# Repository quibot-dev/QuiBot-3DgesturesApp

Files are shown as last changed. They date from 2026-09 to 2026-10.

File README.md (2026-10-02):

# Qui-Bot H₂O
Documentació oficial i codi del Projecte QuiBot (UPC).

🌐 **Lloc web del projecte:** [https://quibot.upc.edu]

Robot humanoide educatiu que introdueix la programació seqüencial i la química
a infants de primària. Es mou per un tauler de joc amb línies negres, seguint
seqüències d'ordres, i manipula líquids de colors amb dues xeringues.

Admet tres vies de control:

- **Blocs de colors.** S'hi introdueixen cubs de fusta i el robot en llegeix el
  color i executa l'acció corresponent. És la via original del projecte.
- **Gestos.** Un sensor davant la cara reconeix sis ordres de moviment, amb
  confirmació abans d'executar-les.
- **Control remot per Wi-Fi.** El robot serveix una pàgina web que s'obre des
  del navegador de qualsevol telèfon o ordinador de la mateixa xarxa, sense
  instal·lar res.

## Contingut del repositori

| Directori | Contingut |
|---|---|
| `3D/` | Peces en STL, fitxers de disseny, model del conjunt en FreeCAD, captures amb l'orientació d'impressió i els paràmetres de cada perfil |
| `PCB/` | Projecte KiCad, fitxers de fabricació en Gerber, esquema elèctric i vista 3D |
| `src/` | Programa de control, servidor web i programes de verificació |
| `doc/` | Llista de material i memòria del treball |
| `User_manual/` | Guia d'ús del robot per a tallers i vídeo de demostració |

La **guia de muntatge**, de trenta-set passos, és l'annex A de la memòria.

## Maquinari

El control corre sobre una **Raspberry Pi Zero W** muntada sobre una placa
dissenyada per al projecte. Els motors pas a pas es governen amb controladors
A4988 i els polsos es generen per programari amb `pigpio`.

Els sensors són el TCS34725 per al color dels blocs, el PAJ7620U2 per als
gestos, el VL53L0X per a la distància als recipients i dos TCRT5000 per al
seguiment de línia, llegits a través d'un convertidor ADS1115. Els ulls són
dues matrius de LED WS2811.

## Posada en marxa

Cal Raspberry Pi OS Lite de 32 bits. El procediment complet és a l'annex D de
la memòria; en resum:

**1. Busos i pins.** Afegiu a `/boot/firmware/config.txt`:

```
dtparam=i2c_arm=on
dtoverlay=i2c-gpio,bus=3,i2c_gpio_sda=0,i2c_gpio_scl=1
gpio=4,5,6=op,dh
```

La tercera línia imposa nivell alt als pins d'habilitació dels controladors des
de l'arrencada i evita que els motors quedin energitzats i brunzint.

**2. Mòdul d'accés als busos:**

```bash
sudo modprobe i2c-dev
echo i2c-dev | sudo tee -a /etc/modules
```

Reinicieu. `ls /dev/i2c-*` ha de mostrar els dos busos.

**3. Entorn de Python:**

```bash
python3 -m venv ~/.venv
~/.venv/bin/pip install pigpio smbus2 flask rpi_ws281x \
    adafruit-circuitpython-ads1x15 \
    adafruit-circuitpython-tcs34725 \
    adafruit-circuitpython-vl53l0x \
    adafruit-extended-bus
```

**4. Dimoni de control dels pins:**

```bash
sudo systemctl enable --now pigpiod
```

**5. Execució:**

```bash
~/.venv/bin/python3 quibot.py
```

El programa escriu a la sortida l'adreça del control remot, que escolta al
port 8000. Per arrencar-lo automàticament amb la màquina, l'annex D descriu el
servei de systemd corresponent.

Els programes de `src/tests/` permeten comprovar els motors i cada sensor per
separat, cosa que convé fer amb la placa encara accessible.

## Procedència i llicències

L'estructura mecànica i el disseny original del robot provenen del projecte
[Qui-Bot H₂O de La Codornella](https://github.com/lacodornella/QuiBot), d'on
surten també les captures d'orientació d'impressió que es reprodueixen aquí.
Dues peces s'han redissenyat i la placa de control és obra de l'equip del
projecte. El control per gestos, el control remot i la documentació són feina
d'aquest treball.

| Element | Llicència |
|---|---|
| Maquinari: peces 3D, PCB i Gerbers | CERN-OHL-S v2 |
| Programari: codi de control | GPL v3 |
| Documentació: guia de muntatge, BOM i manual | CC BY-SA 4.0 |

Totes tres són recíproques: permeten usar, modificar i redistribuir el
material amb la condició que les obres derivades es publiquin en les mateixes
condicions.

> 📢 **Aviseu-nos si feu servir o adapteu aquest material!**  
> Si teniu pensat replicar el projecte, utilitzar aquest material en la vostra recerca o desenvolupar una versió derivada, us agrairem molt que ens ho feu saber enviant un correu a [quibot@upc.edu](mailto:quibot@upc.edu) o obrint una *Issue* en aquest repositori. Això ens ajuda a fer el seguiment de l'impacte del projecte.

---

## 👥 Autors, Equip i Agraïments

* **Investigadors Principals:** Marta Tarrés i Toni Dorado — Grup de Recerca RISS, Universitat Politècnica de Catalunya (UPC).
* **Desenvolupament i Integració (TFG/TFM):** Pau Anguera Comas 
* **Finançament:** Projecte finançat pel Departament d'Igualtat i Feminismes de la Generalitat de Catalunya (`IFE038/24/000087`).

* ## ⚠️ Avís Legal, Seguretat i Suport

* **Exempció de responsabilitat:** Aquest repositori i tots els seus materials es proporcionen "tal com són" (*AS IS*), amb fins exclusivament docents i de recerca. Els autors i la Universitat Politècnica de Catalunya (UPC) no assumeixen cap responsabilitat per danys directes, indirectes o derivats de la fabricació, muntatge, manipulació o ús dels dissenys, circuits o codis d'aquest projecte.
* **Seguretat mecatrònica:** El dispositiu conté components elèctrics i elements mecànics en moviment. Cal prendre les precaucions de seguretat adients durant la seva manipulació i alimentació elèctrica.
* **Atenció i suport tècnic:** Aquest projecte es manté exclusivament en el marc de les activitats de recerca del grup RISS. L'equip investigador no assumeix cap compromís d'oferir assistència tècnica, suport personalitzat o resolució de peticions a tercers usuaris.

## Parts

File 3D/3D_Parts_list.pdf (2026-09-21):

3D printed parts

Name | Printing time | Plastic (g) | Material | Configuration
1 Arms_motors_support_bottom | 2:49:00 | 24 | PLA negre | QuiBot_2
1 Arms_motors_support_top | 3:11:00 | 27 | PLA negre | QuiBot_2
1 Ball_support | 2:13:00 | 18 | PLA blau | QuiBot_3
1 Ball_support_inferior | 0:23:00 | 3 | PLA blau | QuiBot_3
1 Batteries_lid | 3:15:00 | 29 | PLA blau | QuiBot_3
1 Batteries_support | 8:03:00 | 82 | PLA negre | QuiBot_4
1 Big_pulley | 2:17:00 | 21 | PLA negre | QuiBot_7
1 Big_pulley_mirror | 2:17:00 | 21 | PLA negre | QuiBot_7
1 Block_insert | 5:35:00 | 42 | PLA negre | QuiBot_3
1 Body | 41:46:00 | 311 | PLA blau | QuiBot_3
1 Elbow | 1:20:00 | 9 | PLA negre | QuiBot_6
1 Elbow_mirror | 1:20:00 | 9 | PLA negre | QuiBot_6
1 End_arm_bar | 0:05:00 | 1 | PLA negre | QuiBot_2
1 End_arm_bar | 0:05:00 | 1 | PLA negre | QuiBot_2
1 Extrude_head_1 | 1:59:00 | 16 | PLA taronja | QuiBot_3
1 Extrude_head_1 | 1:59:00 | 16 | PLA taronja | QuiBot_3
1 Extrude_head_2 | 1:58:00 | 24 | PLA taronja | QuiBot_3
1 Extrude_head_2 | 1:58:00 | 24 | PLA taronja | QuiBot_3
1 Extrude_head_3 | 1:40:00 | 19 | PLA taronja | QuiBot_3
1 Extrude_head_3 | 1:40:00 | 19 | PLA taronja | QuiBot_3
1 Eyes_support | 2:32:00 | 23 | PLA negre | QuiBot_1
1 Head | 39:32:00 | 240 | PLA taronja | QuiBot_3
1 Head_back | 7:45:00 | 71 | PLA taronja | QuiBot_3
1 Interior_wheel | 5:58:00 | 83 | PLA taronja | QuiBot_1
1 Interior_wheel_mirror | 5:58:00 | 83 | PLA taronja | QuiBot_1
1 L_Motor_support | 21:16:00 | 147 | PLA blau | QuiBot_3
1 Left_arm_spacing_part | 1:07:00 | 9 | PLA negre | QuiBot_3
1 Left_arm_spacing_part_mirror | 1:07:00 | 9 | PLA negre | QuiBot_3
1 Left_assembly_support | 3:57:00 | 33 | PLA negre | QuiBot_5
1 Left_hall_support (opcional) | 0:55:00 | 5 | PLA negre | QuiBot_3
1 Left_hall_support_mirror (opcional) | 0:55:00 | 5 | PLA negre | QuiBot_3
1 Left_hand | 5:39:00 | 51 | PLA taronja | QuiBot_5
1 Left_hand_mirror | 5:39:00 | 51 | PLA taronja | QuiBot_5
1 Line_sensors_support | 0:49:00 | 5 | PLA negre | QuiBot_5
1 Programming_block_magnets_union | 0:21:00 | 3 | PLA taronja | QuiBot_3
1 Pusher_1 | 0:38:00 | 4 | PLA negre | QuiBot_5
1 Pusher_1_mirror | 0:39:00 | 4 | PLA negre | QuiBot_5
1 Pusher_2 | 0:32:00 | 4 | PLA negre | QuiBot_5
1 Pusher_2_mirror | 0:32:00 | 4 | PLA negre | QuiBot_5
1 Pusher_stopper | 0:20:00 | 3 | PLA negre | QuiBot_3
1 Pusher_stopper_top | 1:28:00 | 11 | PLA negre | QuiBot_3
1 R_Motor_support_mirror | 20:32:00 | 143 | PLA blau | QuiBot_3
1 Right_assembly_support_mirror | 4:11:00 | 36 | PLA negre | QuiBot_5
1 Shoulder | 2:26:00 | 19 | PLA negre | QuiBot_6
1 Shoulder_mirror | 2:26:00 | 19 | PLA negre | QuiBot_6
1 Syringe_hall_sensor_support (opcional) | 0:22:00 | 2 | PLA negre | QuiBot_3
1 Syringe_lifter | 3:07:00 | 19 | PLA negre | QuiBot_3
1 Tension_screw_fixing_part | 0:46:00 | 5 | PLA negre | QuiBot_5
1 Transparent_face | 8:27:00 | 81 | PLA transparent | QuiBot_4
1 Union_and_cables_support | 1:00:00 | 8 | PLA negre | QuiBot_2
1 Wheel | 7:04:00 | 93 | PLA negre | QuiBot_2
1 Wheel_mirror | 7:04:00 | 93 | PLA negre | QuiBot_2
Total: | 250:57:00 | 2082

Printer configurations

| | QuiBot_1 | QuiBot_2 | QuiBot_3 | QuiBot_4 | QuiBot_5 | QuiBot_6 | QuiBot_7
Quality | Layer Height | 0.2 | 0.2 | 0.15 | 0.2 | 0.15 | 0.15 | 0.2
| Initial Layer Height | 0.15 | 0.15 | 0.15 | 0.15 | 0.15 | 0.15 | 0.15
Walls | Wall thikness | 0.8 | 0.8 | 0.8 | 2.0 | 2.0 | 0.8 | 0.8
Top/Bottom | Top/bottom pattern | Lines | Lines | Lines | Lines | Lines | Lines | Lines
| Bottom pattern initial layer | Concentric | Lines | Lines | Lines | Lines | Lines | Lines
Infill | Infill density | 10% | 25% | 15% | 15% | 40% | 50% | 25%
Material | Printing temperature | 200ºC | 200ºC | 200ºC | 200ºC | 200ºC | 200ºC | 200ºC
| Speed | 60 mm/s | 40 mm/s | 50 mm/s | 50 mm/s | 50 mm/s | 50 mm/s | 30 mm/s
Support | Generate support | | 1 | 1 | 1 | 1 | 1 | 1
| Support Overhang Angle | | 84º | 84º | 84º | 84º | 84º | 84º

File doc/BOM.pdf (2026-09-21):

Material

Component | Funció | Preu unitari Unitats | Paquet | Cost de compraBotiga | Enllaç
MOVIMENT I TRACCIÓ
Motor pas a pas amb reductor planetari | Tracció de les dues rodes | 31,74 € | 2 | 1 | 63,48 € | Amazon
Sensor de línia TCRT5000 | Seguiment de la línia del tauler | 0,90 € | 2 | 10 | 9,00 € | Amazon
Sensor de distància VL53L0X | Detecció dels recipients | 5,99 € | 1 | 1 | 5,99 € | Amazon
BRAÇOS I XERINGA
Motor pas a pas NEMA 17 | Dos braços i motor de la xeringa | 11,91 € | 3 | 1 | 35,73 € | Amazon
Xeringa de 100 mL amb tub | Aspiració i dosificació del líquid | 3,66 € | 2 | 3 | 10,98 € | Amazon
Barra roscada lineal de 18 cm | Accionament de l'èmbol de les xeringues | 14,99 € | 1 | 1 | 14,99 € | Amazon
Acoblament flexible de 5 a 8 mm | Uneix el motor amb la barra roscada | 3,49 € | 1 | 4 | 13,96 € | Amazon
Politja dentada 2GT de 20 dents | Reducció del moviment dels braços | 9,20 € | 2 | 1 | 18,40 € | Amazon
Corretja GT2 de 200 mm | Transmissió als braços | 1,50 € | 2 | 10 | 15,00 € | Amazon
Rodament 6808ZZ (40×52×7 mm) | Guiatge exterior dels braços | 3,48 € | 2 | 4 | 13,92 € | Amazon
Rodament 604-609 2RS | Guiatge interior dels braços | 1,40 € | 4 | 10 | 14,00 € | Amazon
Rodament lineal LM8UU (8 mm) | Guiatge de les xeringues | 2,42 € | 2 | 12 | 29,04 € | Amazon
Imant de neodimi N52 (8×3 mm) | Unió magnètica del bloc programador | 0,27 € | 4 | 40 | 10,80 € | Amazon
INTERACCIÓ AMB L'USUARI
Sensor de color TCS34725 | Lectura del color dels blocs | 6,00 € | 1 | 2 | 12,00 € | Amazon
Servomotor MG90S | Expulsió dels blocs un cop llegits | 4,50 € | 1 | 2 | 9,00 € | Amazon
Sensor de gestos PAJ7620U2 | Reconeixement dels gestos de la mà | 11,99 € | 1 | 1 | 11,99 € | Amazon
Matriu de LED 8×8 WS2811 | Ulls: única sortida d'informació del robot | 3,24 € | 2 | 3 | 9,72 € | Amazon
CONTROL I ALIMENTACIÓ
Placa de control (fabricació) | Circuit imprès sense components | 227,48 € | 1 | 1 | 227,48 € | PCBWay
Components de la placa | Condensadors, resistències, transistors i capçaleres | 21,94 € | 1 | 1 | 21,94 € | Botiga comercial elect
Controlador de motor A4988 | Un per a cada motor pas a pas | 3,84 € | 5 | 5 | 19,20 € | Amazon
Raspberry Pi Zero W | Unitat de control del robot | 32,90 € | 1 | 1 | 32,90 € | Amazon
Targeta microSD de 32 GB | Sistema operatiu i programa de control | 19,06 € | 1 | 1 | 19,06 € | Amazon
Convertidor A/D ADS1115 | Lectura dels sensors de línia | 3,30 € | 1 | 3 | 9,90 € | Amazon
Bateria externa (20 V i 5 V) | Alimentació del robot per USB-C | 63,64 € | 1 | 1 | 63,64 € | Amazon
Mòdul USB-C Trigger 9-20 V | Negociació de la tensió dels motors | 1,80 € | 2 | 5 | 9,00 € | Amazon
Cable microHDMI a VGA | Consulta de l'adreça del robot en la posada en marxa | 13,99 € | 1 | 1 | 13,99 € | Amazon
ESTRUCTURA I FABRICACIÓ
Filament PLA negre (1 kg) | Impressió de 29 peces (648 g) | 13,99 € | 1 | 1 | 13,99 € | Amazon
Filament PLA blau (1 kg) | Impressió de 6 peces (651 g) | 15,99 € | 1 | 1 | 15,99 € | Amazon
Filament PLA taronja (1 kg) | Impressió de 13 peces (700 g) | 15,99 € | 1 | 1 | 15,99 € | Amazon
Filament PLA transparent (1 kg) | Cara frontal del cap (81 g) | 17,99 € | 1 | 1 | 17,99 € | Amazon
Tub d'alumini 6×4 mm (1 m) ⌀ | Estructura interior; 10 talls | 3,75 € | 2 | 1 | 7,50 € | FesMés
Tub d'alumini 8×6 mm (1 m) ⌀ | Estructura interior; 12 talls | 3,95 € | 2 | 1 | 7,90 € | FesMés
Cargoleria DIN 912, 934 i 125 | 154 cargols, 8 volanderes i 11 femelles | 36,69 € | 1 | 1 | 36,69 € | Inter Metal
ELEMENTS DEL JOC
Lona de plàstic (1,4×2 m) | Tauler per on es mou el robot | 18,00 € | 1 | 1 | 18,00 € | Plàstics Pujol
Cubs de fusta de colors | Blocs de programació | 27,12 € | 1 | 1 | 27,12 € | Amazon
Recipient de plàstic | Contenidors del líquid, als vèrtexs | 3,50 € | 4 | 1 | 14,00 € | Xinos
Tub de silicona 4×6 mm (160 cm) ⌀ | Porta el líquid de les xeringues a les mans | 8,99 € | 1 | 1 | 8,99 € | Amazon
Tub corrugat 32 mm (40 cm) ⌀ | Recobriment exterior dels braços | 8,99 € | 1 | 1 | 8,99 € | Amazon
TOTAL del material que va dins del robot | 799,91 €
TOTAL del desemborsament en compres | 908,26 €

https://amzn.eu/d/0bHJ65rQhttps://amzn.eu/d/0gY5e2cHhttps://amzn.eu/d/0fq382lZ

https://amzn.eu/d/0ahWBRaohttps://amzn.eu/d/0dnn4ptlhttps://amzn.eu/d/0eNuT9R0https://amzn.eu/d/08H7Wn4qhttps://amzn.eu/d/00PCee4bhttps://amzn.eu/d/01LhTFNuhttps://a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

https://amzn.eu/d/04wjB8VRhttps://amzn.eu/d/0ejjzcFlhttps://amzn.eu/d/00GRGy5Vhttps://amzn.eu/d/0fHxGHRr

https://amzn.eu/d/0bKpJpKYhttps://amzn.eu/d/0hONPyERhttps://amzn.eu/d/01s6eHg2https://amzn.eu/d/09HGVsxPhttps://amzn.eu/d/03E54GFUhttps://amzn.eu/d/042zraUVhttps://a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

https://amzn.eu/d/0fHSgWqahttps://amzn.eu/d/04fMypw1
https://amzn.eu/d/03HETHHK
https://amzn.eu/d/05oxmYt9https://www.fesmes.com/perfils-d-alumini/295205004-tub-rodo-alumini-anoditzat-plata-8013237011116.htmlhttps://www.fesmes.com/perfils-d-alum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

https://amzn.eu/d/02Y8XqlD

https://amzn.eu/d/03qYdG2Ohttps://amzn.eu/d/01d3ZOWd

### Cargoleria

Element | Mida | Unitats
Cargol DIN 912 | M3×6 | 14
Cargol DIN 912 | M3×10 | 64
Cargol DIN 912 | M3×12 | 2
Cargol DIN 912 | M3×16 | 13
Cargol DIN 912 | M3×20 | 14
Cargol DIN 912 | M3×30 | 8
Cargol DIN 912 | M3×35 | 21
Cargol DIN 912 | M3×50 | 1
Cargol DIN 912 | M4×20 | 16
Cargol DIN 912 | M4×80 | 1
Volandera DIN 125 | M3 | 8
Femella DIN 934 | M3 | 6
Femella DIN 934 | M4 | 5
Total de cargols | | 154
Total de volanderes | | 8
Total de femelles | | 11

Recompte obtingut de la guia de muntatge (annex A de la memòria).

### Talls de tub

Diàmetre | Llargada | Unitats Funció
⌀8×6 mm | 380 mm | 2 | Travessen el cos i el bloc dels motors
⌀8×6 mm | 125 mm | 2 | Unió del dipòsit amb la base
⌀8×6 mm | 100 mm | 4 | Espatlles
⌀8×6 mm | 65 mm | 3 | Separador de la base i eixos dels braços
⌀8×6 mm | 45 mm | 1 | Tancament del mecanisme del sensor de color
⌀6×4 mm | 310 mm | 1 | Dipòsit de blocs
⌀6×4 mm | 290 mm | 2 | Dipòsit de blocs
⌀6×4 mm | 220 mm | 1 | Dipòsit de blocs
⌀6×4 mm | 105 mm | 4 | Avantbraços
⌀6×4 mm | 65 mm | 2 | Van dins dels de 8, roscats interiorment ⌀

### Repartiment en barres d'un metre (dues de cada diàmetre):

8, barra 1: 380 + 380 + 125 | consum 885 mm, sobren 115 ⌀
8, barra 2: 125 + 100×4 + 65×3 + 45 | consum 765 mm, sobren 235 ⌀
6, barra 1: 310 + 290 + 290 | consum 890 mm, sobren 110 ⌀
6, barra 2: 220 + 105×4 + 65×2 | consum 770 mm, sobren 230 ⌀

Recompte obtingut de la guia de muntatge (annex A de la memòria).

Electrònica de la placa

Component | Característiques | Referència a l'esquema | Unitats | Observacions
Resistència 330 Ω | 1/4 W, axial | R1 | 1
Resistència 220 Ω | 1/4 W, axial | R7, R10 | 2
Resistència 680 Ω | 1/4 W, axial | R3, R8 | 2
Resistència 4,7 kΩ | 1/4 W, axial | R4, R9 | 2
Resistència 10 kΩ | 1/4 W, axial | R5, R6 | 2
Transistor 2N3904 | NPN, TO-92 | Q1, Q2 | 2
Condensador 1000 µF / 6,3 V | Radial 8 mm, pas 2,5 mm ⌀ | C1 | 1
Condensador 470 µF / 35V | Radial 10 mm, pas 5 mm ⌀ | C2 | 1
Condensador 100 µF / 16V | Radial 5 mm, pas 2,5 mm ⌀ | C6 | | 1 Desacoblament del servomotor
Condensador 100 µF / 35V | Radial 6,3 mm, pas 2,5 mm ⌀ | C4 a C5 i C7 a C9 | | 5 Desacoblament dels controladors
Tira de pins mascle 1×3 | Pas 2,54 mm | E_LA1, E_RA1, E_SY1, SERVO1, LED1 | | 5 Finals de cursa, servomotor i ulls
Tira de pins mascle 1×4 | Pas 2,54 mm | M_LW1, M_RW1, M_LA1, M_RA1, M_SY1, CO | 6 Motors i sensor de color
Tira de pins mascle 1×5 | Pas 2,54 mm | G1 | | 1 Sensor de gestos
Tira de pins mascle 1×6 | Pas 2,54 mm | MIC1 | | 1 Micròfon
Tira de pins femella 1×6 | Pas 2,54 mm | DIST1 | | 1 Sensor de distància
Tira de pins mascle 1×7 | Pas 2,54 mm | AMP1 | | 1 Amplificador d'àudio
Tira de pins femella 1×10 | Pas 2,54 mm | ADC1 | | 1 Convertidor ADS1115
Tira de pins femella 1×20 | Pas 2,54 mm | RASP1 | | 2 Raspberry Pi
Tira de pins femella 1x8 | Pas 2,54 mm | L_WHEEL1, R_WHEEL1, L_ARM1, R_ARM1, | | 10 Dos per controlador

Cost conjunt: 21,94 €
Tots els components són THT

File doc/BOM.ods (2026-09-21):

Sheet: Material
Component | Funció | Preu unitari | Unitats | Paquet | Cost de compra | Botiga | Enllaç
MOVIMENT I TRACCIÓ
Motor pas a pas amb reductor planetari | Tracció de les dues rodes | 31,74 € | 2 | 1 | 63,48 € | Amazon | https://amzn.eu/d/0bHJ65rQ
Sensor de línia TCRT5000 | Seguiment de la línia del tauler | 0,90 € | 2 | 10 | 9,00 € | Amazon | https://amzn.eu/d/0gY5e2cH
Sensor de distància VL53L0X | Detecció dels recipients | 5,99 € | 1 | 1 | 5,99 € | Amazon | https://amzn.eu/d/0fq382lZ
BRAÇOS I XERINGA
Motor pas a pas NEMA 17 | Dos braços i motor de la xeringa | 11,91 € | 3 | 1 | 35,73 € | Amazon | https://amzn.eu/d/0ahWBRao
Xeringa de 100 mL amb tub | Aspiració i dosificació del líquid | 3,66 € | 2 | 3 | 10,98 € | Amazon | https://amzn.eu/d/0dnn4ptl
Barra roscada lineal de 18 cm | Accionament de l'èmbol de les xeringues | 14,99 € | 1 | 1 | 14,99 € | Amazon | https://amzn.eu/d/0eNuT9R0
Acoblament flexible de 5 a 8 mm | Uneix el motor amb la barra roscada | 3,49 € | 1 | 4 | 13,96 € | Amazon | https://amzn.eu/d/08H7Wn4q
Politja dentada 2GT de 20 dents | Reducció del moviment dels braços | 9,20 € | 2 | 1 | 18,40 € | Amazon | https://amzn.eu/d/00PCee4b
Corretja GT2 de 200 mm | Transmissió als braços | 1,50 € | 2 | 10 | 15,00 € | Amazon | https://amzn.eu/d/01LhTFNu
Rodament 6808ZZ (40×52×7 mm) | Guiatge exterior dels braços | 3,48 € | 2 | 4 | 13,92 € | Amazon | https://amzn.eu/d/0bqTrvEY
Rodament 604-609 2RS | Guiatge interior dels braços | 1,40 € | 4 | 10 | 14,00 € | Amazon | https://amzn.eu/d/056e36mP
Rodament lineal LM8UU (8 mm) | Guiatge de les xeringues | 2,42 € | 2 | 12 | 29,04 € | Amazon | https://amzn.eu/d/0b6RFzTl
Imant de neodimi N52 (8×3 mm) | Unió magnètica del bloc programador | 0,27 € | 4 | 40 | 10,80 € | Amazon | https://amzn.eu/d/05W1UBqO
INTERACCIÓ AMB L'USUARI
Sensor de color TCS34725 | Lectura del color dels blocs | 6,00 € | 1 | 2 | 12,00 € | Amazon | https://amzn.eu/d/04wjB8VR
Servomotor MG90S | Expulsió dels blocs un cop llegits | 4,50 € | 1 | 2 | 9,00 € | Amazon | https://amzn.eu/d/0ejjzcFl
Sensor de gestos PAJ7620U2 | Reconeixement dels gestos de la mà | 11,99 € | 1 | 1 | 11,99 € | Amazon | https://amzn.eu/d/00GRGy5V
Matriu de LED 8×8 WS2811 | Ulls: única sortida d'informació del robot | 3,24 € | 2 | 3 | 9,72 € | Amazon | https://amzn.eu/d/0fHxGHRr
CONTROL I ALIMENTACIÓ
Placa de control (fabricació) | Circuit imprès sense components | 227,48 € | 1 | 1 | 227,48 € | PCBWay
Components de la placa | Condensadors, resistències, transistors i capçaleres | 21,94 € | 1 | 1 | 21,94 € | Botiga comercial electrònica (Manresa)
Controlador de motor A4988 | Un per a cada motor pas a pas | 3,84 € | 5 | 5 | 19,20 € | Amazon | https://amzn.eu/d/0bKpJpKY
Raspberry Pi Zero W | Unitat de control del robot | 32,90 € | 1 | 1 | 32,90 € | Amazon | https://amzn.eu/d/0hONPyER
Targeta microSD de 32 GB | Sistema operatiu i programa de control | 19,06 € | 1 | 1 | 19,06 € | Amazon | https://amzn.eu/d/01s6eHg2
Convertidor A/D ADS1115 | Lectura dels sensors de línia | 3,30 € | 1 | 3 | 9,90 € | Amazon | https://amzn.eu/d/09HGVsxP
Bateria externa (20 V i 5 V) | Alimentació del robot per USB-C | 63,64 € | 1 | 1 | 63,64 € | Amazon | https://amzn.eu/d/03E54GFU
Mòdul USB-C Trigger 9-20 V | Negociació de la tensió dels motors | 1,80 € | 2 | 5 | 9,00 € | Amazon | https://amzn.eu/d/042zraUV
Cable microHDMI a VGA | Consulta de l'adreça del robot en la posada en marxa | 13,99 € | 1 | 1 | 13,99 € | Amazon | https://amzn.eu/d/0bYeHMyn
ESTRUCTURA I FABRICACIÓ
Filament PLA negre (1 kg) | Impressió de 29 peces (648 g) | 13,99 € | 1 | 1 | 13,99 € | Amazon | https://amzn.eu/d/0fHSgWqa
Filament PLA blau (1 kg) | Impressió de 6 peces (651 g) | 15,99 € | 1 | 1 | 15,99 € | Amazon | https://amzn.eu/d/04fMypw1
Filament PLA taronja (1 kg) | Impressió de 13 peces (700 g) | 15,99 € | 1 | 1 | 15,99 € | Amazon | https://amzn.eu/d/03HETHHK
Filament PLA transparent (1 kg) | Cara frontal del cap (81 g) | 17,99 € | 1 | 1 | 17,99 € | Amazon | https://amzn.eu/d/05oxmYt9
Tub d'alumini ⌀6×4 mm (1 m) | Estructura interior; 10 talls | 3,75 € | 2 | 1 | 7,50 € | FesMés | https://www.fesmes.com/perfils-d-alumini/295205004-tub-rodo-alumini-anoditzat-plata-8013237011116.html
Tub d'alumini ⌀8×6 mm (1 m) | Estructura interior; 12 talls | 3,95 € | 2 | 1 | 7,90 € | FesMés | https://www.fesmes.com/perfils-d-alumini/295205004-tub-rodo-alumini-anoditzat-plata-8013237011116.html
Cargoleria DIN 912, 934 i 125 | 154 cargols, 8 volanderes i 11 femelles | 36,69 € | 1 | 1 | 36,69 € | Inter Metal
ELEMENTS DEL JOC
Lona de plàstic (1,4×2 m) | Tauler per on es mou el robot | 18,00 € | 1 | 1 | 18,00 € | Plàstics Pujol
Cubs de fusta de colors | Blocs de programació | 27,12 € | 1 | 1 | 27,12 € | Amazon | https://amzn.eu/d/02Y8XqlD
Recipient de plàstic | Contenidors del líquid, als vèrtexs | 3,50 € | 4 | 1 | 14,00 € | Xinos
Tub de silicona ⌀4×6 mm (160 cm) | Porta el líquid de les xeringues a les mans | 8,99 € | 1 | 1 | 8,99 € | Amazon | https://amzn.eu/d/03qYdG2O
Tub corrugat ⌀32 mm (40 cm) | Recobriment exterior dels braços | 8,99 € | 1 | 1 | 8,99 € | Amazon | https://amzn.eu/d/01d3ZOWd
TOTAL del material que va dins del robot |  |  |  |  | 799,91 €
TOTAL del desemborsament en compres |  |  |  |  | 908,26 €

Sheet: Cargoleria
Element | Mida | Unitats
Cargol DIN 912 | M3×6 | 14
Cargol DIN 912 | M3×10 | 64
Cargol DIN 912 | M3×12 | 2
Cargol DIN 912 | M3×16 | 13
Cargol DIN 912 | M3×20 | 14
Cargol DIN 912 | M3×30 | 8
Cargol DIN 912 | M3×35 | 21
Cargol DIN 912 | M3×50 | 1
Cargol DIN 912 | M4×20 | 16
Cargol DIN 912 | M4×80 | 1
Volandera DIN 125 | M3 | 8
Femella DIN 934 | M3 | 6
Femella DIN 934 | M4 | 5
Total de cargols |  | 154
Total de volanderes |  | 8
Total de femelles |  | 11
Recompte obtingut de la guia de muntatge (annex A de la memòria).

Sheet: Talls de tub
Diàmetre | Llargada | Unitats | Funció
⌀8×6 mm | 380 mm | 2 | Travessen el cos i el bloc dels motors
⌀8×6 mm | 125 mm | 2 | Unió del dipòsit amb la base
⌀8×6 mm | 100 mm | 4 | Espatlles
⌀8×6 mm | 65 mm | 3 | Separador de la base i eixos dels braços
⌀8×6 mm | 45 mm | 1 | Tancament del mecanisme del sensor de color
⌀6×4 mm | 310 mm | 1 | Dipòsit de blocs
⌀6×4 mm | 290 mm | 2 | Dipòsit de blocs
⌀6×4 mm | 220 mm | 1 | Dipòsit de blocs
⌀6×4 mm | 105 mm | 4 | Avantbraços
⌀6×4 mm | 65 mm | 2 | Van dins dels de ⌀8, roscats interiorment
Repartiment en barres d'un metre (dues de cada diàmetre):
⌀8, barra 1: 380 + 380 + 125 consum 885 mm, sobren 115
⌀8, barra 2: 125 + 100×4 + 65×3 + 45 consum 765 mm, sobren 235
⌀6, barra 1: 310 + 290 + 290 consum 890 mm, sobren 110
⌀6, barra 2: 220 + 105×4 + 65×2 consum 770 mm, sobren 230
Recompte obtingut de la guia de muntatge (annex A de la memòria).

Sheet: Electrònica de la placa
Component | Característiques | Referència a l'esquema | Unitats | Observacions
Resistència 330 Ω | 1/4 W, axial | R1 | 1
Resistència 220 Ω | 1/4 W, axial | R7, R10 | 2
Resistència 680 Ω | 1/4 W, axial | R3, R8 | 2
Resistència 4,7 kΩ | 1/4 W, axial | R4, R9 | 2
Resistència 10 kΩ | 1/4 W, axial | R5, R6 | 2
Transistor 2N3904 | NPN, TO-92 | Q1, Q2 | 2
Condensador 1000 µF / 6,3 V | Radial ⌀8 mm, pas 2,5 mm | C1 | 1
Condensador 470 µF / 35V | Radial ⌀10 mm, pas 5 mm | C2 | 1
Condensador 100 µF / 16V | Radial ⌀5 mm, pas 2,5 mm | C6 | 1 | Desacoblament del servomotor
Condensador 100 µF / 35V | Radial ⌀6,3 mm, pas 2,5 mm | C4 a C5 i C7 a C9 | 5 | Desacoblament dels controladors
Tira de pins mascle 1×3 | Pas 2,54 mm | E_LA1, E_RA1, E_SY1, SERVO1, LED1 | 5 | Finals de cursa, servomotor i ulls
Tira de pins mascle 1×4 | Pas 2,54 mm | M_LW1, M_RW1, M_LA1, M_RA1, M_SY1, COL1 | 6 | Motors i sensor de color
Tira de pins mascle 1×5 | Pas 2,54 mm | G1 | 1 | Sensor de gestos
Tira de pins mascle 1×6 | Pas 2,54 mm | MIC1 | 1 | Micròfon
Tira de pins femella 1×6 | Pas 2,54 mm | DIST1 | 1 | Sensor de distància
Tira de pins mascle 1×7 | Pas 2,54 mm | AMP1 | 1 | Amplificador d'àudio
Tira de pins femella 1×10 | Pas 2,54 mm | ADC1 | 1 | Convertidor ADS1115
Tira de pins femella 1×20 | Pas 2,54 mm | RASP1 | 2 | Raspberry Pi
Tira de pins femella 1x8 | Pas 2,54 mm | L_WHEEL1, R_WHEEL1, L_ARM1, R_ARM1, SYRINGE1 | 10 | Dos per controlador
Cost conjunt: 21,94 €
Tots els components són THT

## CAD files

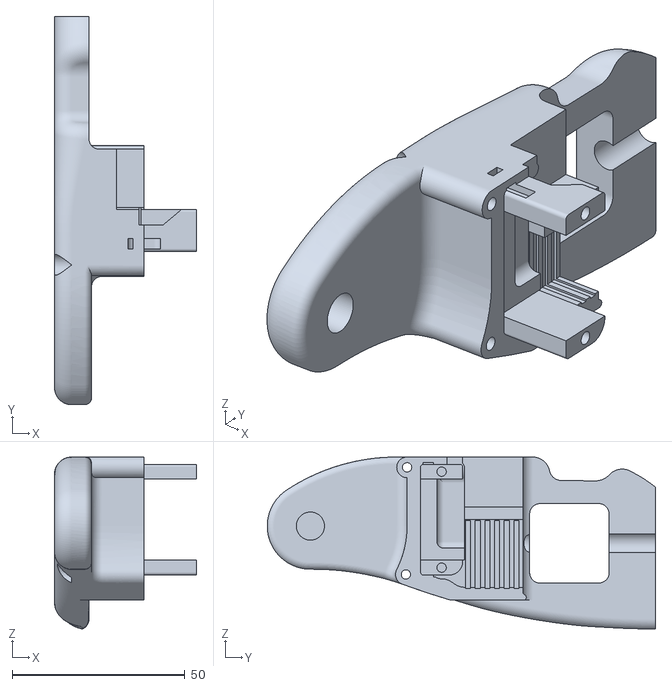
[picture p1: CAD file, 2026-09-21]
3D/STL/Right_assembly_support_mirror.STL
41.2 x 112.5 x 49.8

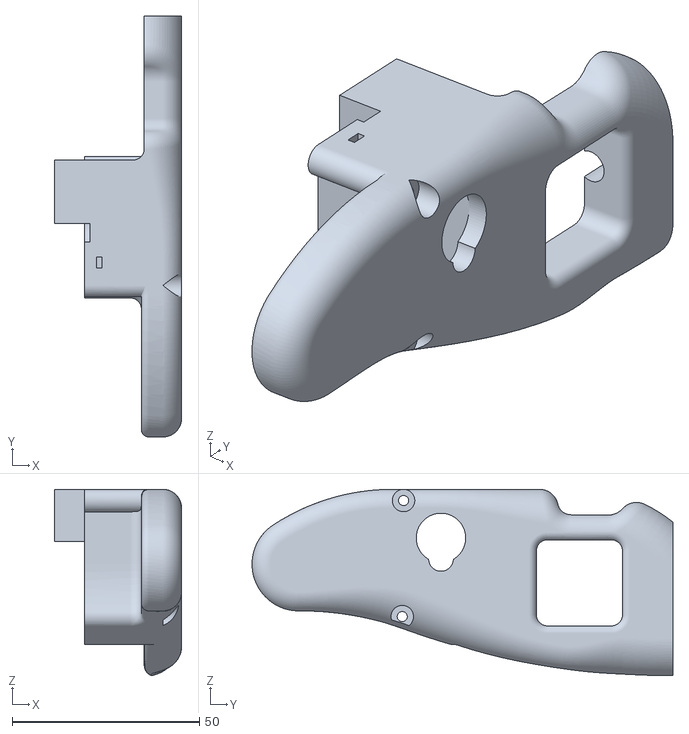
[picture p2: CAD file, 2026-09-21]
3D/STL/Left_assembly_support.STL
34.0 x 112.5 x 49.8

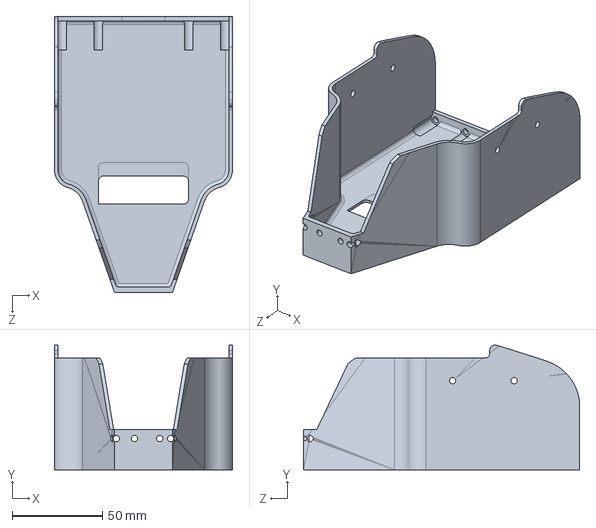
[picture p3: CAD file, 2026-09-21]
3D/SLDPRT/Batteries_support.SLDPRT
98.4 x 69.0 x 152.7 mm

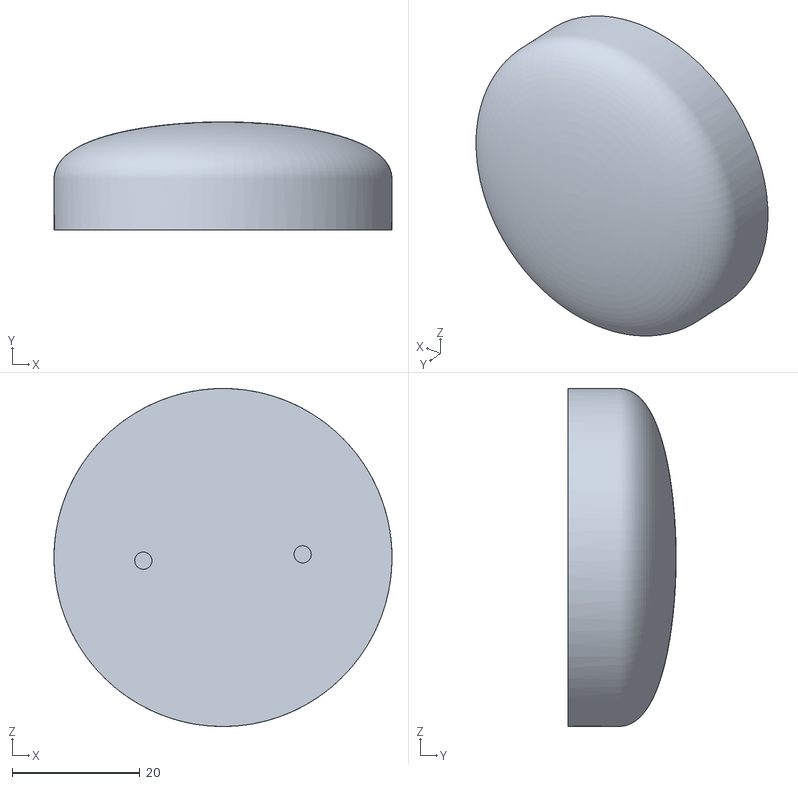
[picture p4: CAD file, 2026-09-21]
3D/STL/Extrude_head_3.STL
53.0 x 17.0 x 53.0

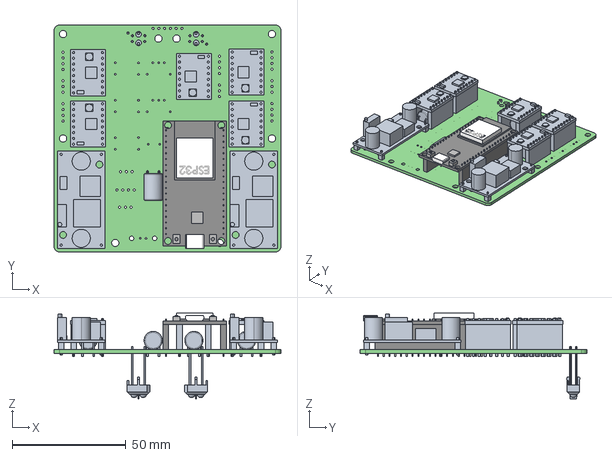
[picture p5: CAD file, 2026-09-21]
PCB/kicad/PCB_QuiBot.step
100.0 x 100.0 x 37.7 mm
_autosave-PCB_QuiBot PCB

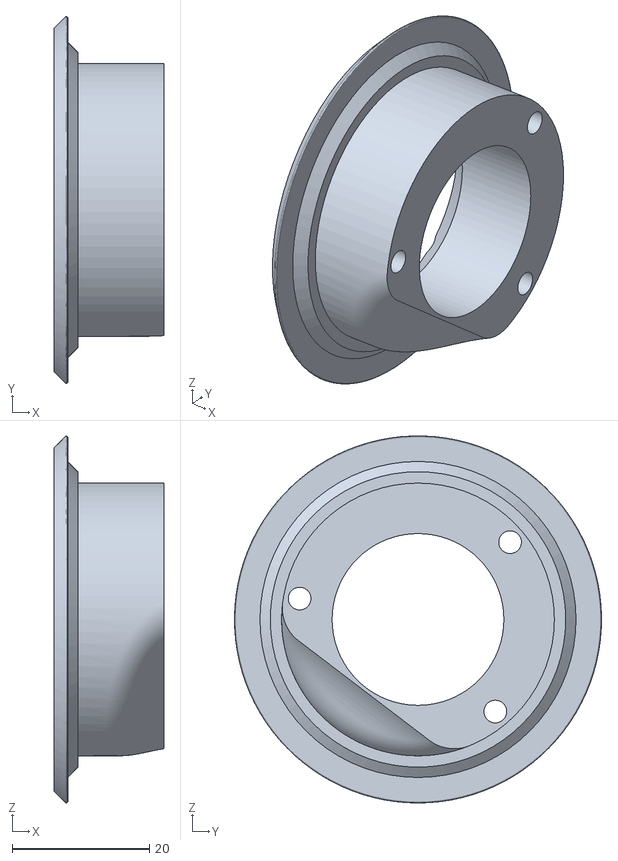
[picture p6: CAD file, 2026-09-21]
3D/STL/Left_arm_spacing_part_mirror.STL
16.0 x 53.4 x 53.4

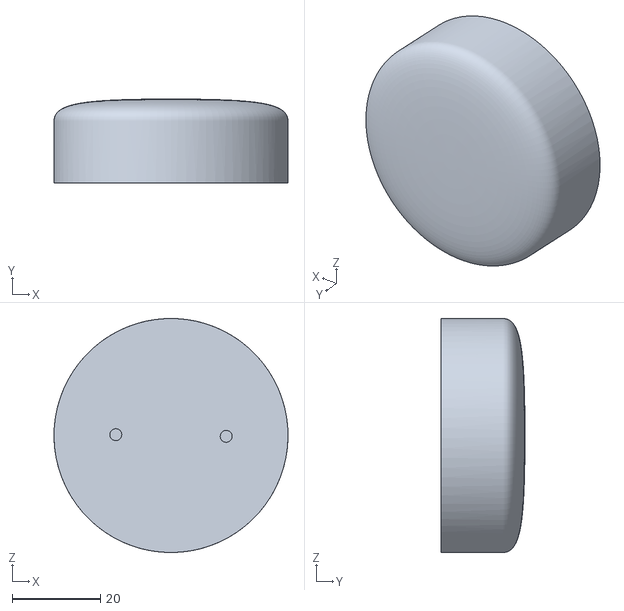
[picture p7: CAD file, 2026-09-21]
3D/STL/Extrude_head_2.STL
53.0 x 19.0 x 53.0

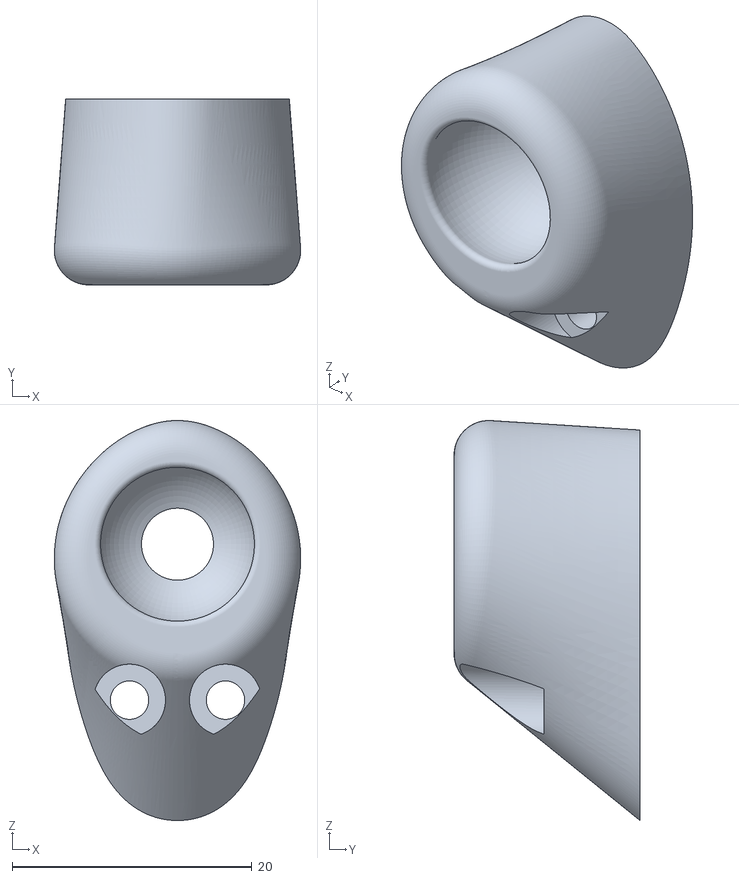
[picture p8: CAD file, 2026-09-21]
3D/STL/Ball_support_inferior.STL
20.5 x 15.5 x 33.3

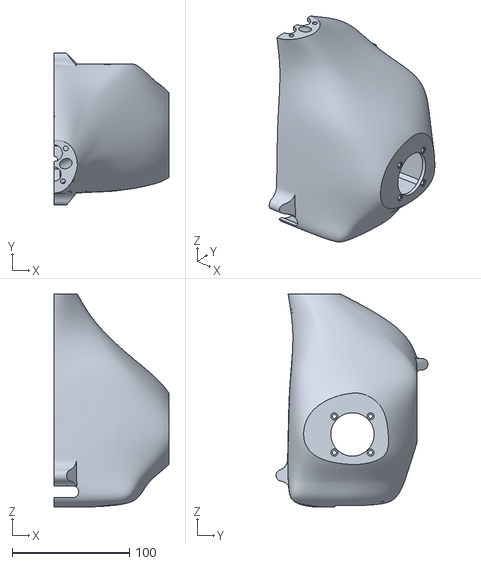
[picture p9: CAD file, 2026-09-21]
3D/STL/R_Motor_support_mirror.STL
98.0 x 129.8 x 182.0

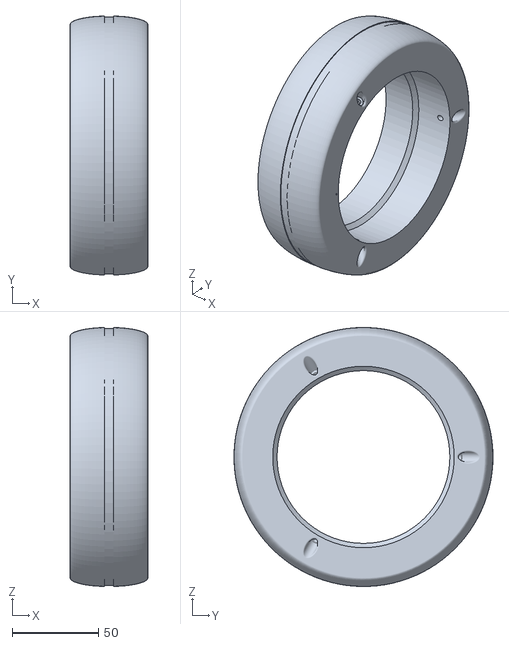
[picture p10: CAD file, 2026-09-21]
3D/STL/Wheel_mirror.STL
45.0 x 149.9 x 149.9

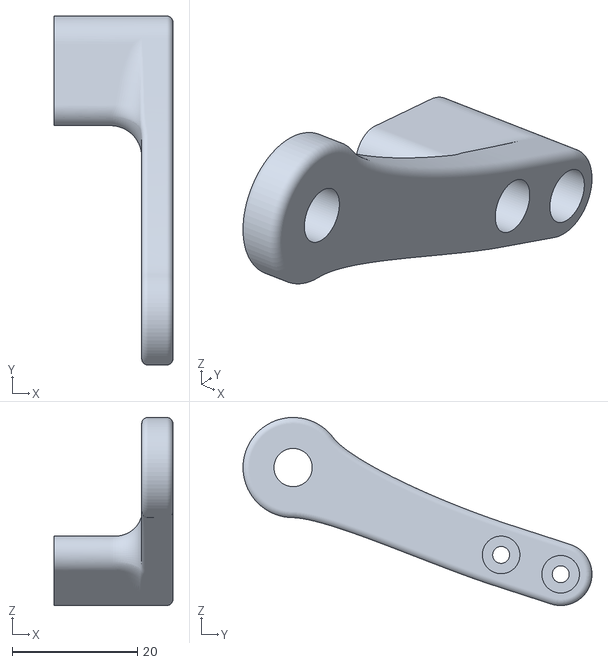
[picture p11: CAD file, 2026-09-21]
3D/STL/Pusher_1_mirror.STL
19.0 x 55.7 x 30.0

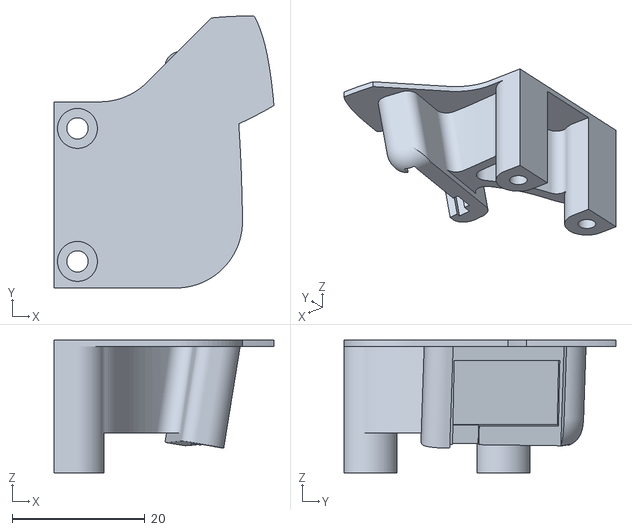
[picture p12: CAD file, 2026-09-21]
3D/STL/Left_hall_support.STL
33.0 x 40.9 x 20.0

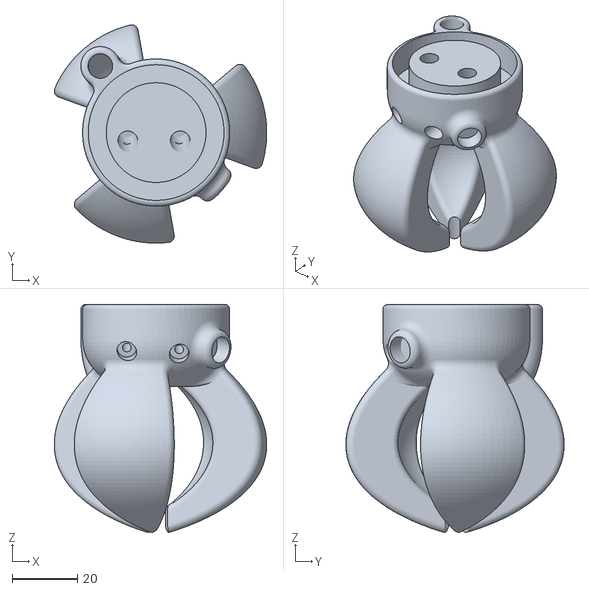
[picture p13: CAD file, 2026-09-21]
3D/STL/Left_hand.STL
65.0 x 66.7 x 69.7

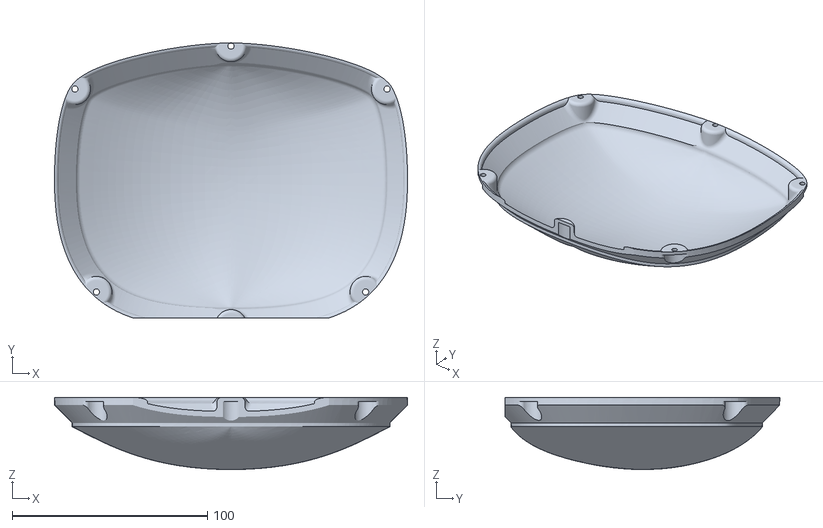
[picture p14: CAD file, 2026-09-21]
3D/STL/Transparent_face.STL
180.9 x 141.0 x 37.0

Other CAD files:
3D/STL/Pusher_1.STL
3D/STL/Arms_motors_support_top.STL
3D/STL/Syringe_hall_sensor_support.STL
3D/STL/Pusher_2.STL
3D/STL/Arms_motors_support_bottom.STL
3D/STL/Ball_support.STL
3D/STL/Batteries_lid.STL
3D/STL/Batteries_support.STL
3D/STL/Big_pulley.STL
3D/STL/Big_pulley_mirror.STL
3D/STL/Block_insert.STL
3D/STL/Body.STL
3D/STL/Elbow.STL
3D/STL/Elbow_mirror.STL
3D/STL/End_arm_bar.STL
3D/STL/Extrude_head_1.STL
3D/STL/Eyes_support.STL
3D/STL/Head.STL
3D/STL/Head_back.STL
3D/STL/Interior_wheel.STL
3D/STL/Interior_wheel_mirror.STL
3D/STL/L_Motor_support.STL
3D/STL/Left_arm_spacing_part.STL
3D/STL/Left_hall_support_mirror.STL
3D/STL/Left_hand_mirror.STL
3D/STL/Line_sensors_support.STL
3D/STL/Programming_block_magnets_union.STL
3D/STL/Pusher_2_mirror.STL
3D/STL/Pusher_stopper.STL
3D/STL/Pusher_stopper_top.STL
3D/STL/Shoulder.STL
3D/STL/Shoulder_mirror.STL
3D/STL/Syringe_lifter.STL
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

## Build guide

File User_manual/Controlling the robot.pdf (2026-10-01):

# Controlar el robot amb gestos i des del mòbil

Qui-Bot H2O • guia ràpida per a tallers

Abans de començar

### 1. Poseu el robot sobre la línia negra del tauler i

endolleu-li la bateria.

### 2. El robot busca sol la posició inicial dels braços i de la

xeringa, i puja els braços perquè no tapin el sensor de gestos. Quan s’encenen els ulls ja està a punt.

3. El robot arrenca en mode blocs, igual que sempre. Els gestos i el comandament des del mòbil s’hi afegeixen: no substitueixen res.

Jugar amb gestos

Feu els gestos amb la mà a uns 15 cm de la cara del robot, posant-vos-hi al davant, cara a cara.

### 1. Saludeu amb la mà per passar del mode blocs al

mode gestos. Els ulls us diuen a quin mode heu entrat. Tornar a saludar us retorna als blocs.

### 2. Feu el gest de l’acció que voleu. Els ulls parpelle-

gen del color de l’acció: el robot ha entès la comanda i espera que la confirmeu.

### 3. Confirmeu amb el gest cap amunt. Apareix un tic

verd i el robot executa l’acció.

Per anul·lar-la, feu el gest cap avall: sortirà una creu vermella. Si no responeu en deu segons, també s’anul·la.

Per què cal confirmar: amb infants al voltant, el sensor veu moltes mans que no li parlen a ell. Sense confirmació el robot es mouria tot sol.

Després de cada acció espereu un segon abans del gest següent. El robot oblida a posta els gestos fets mentre es movia.

Els gestos i què fan

↑ Avança una casella

↓ Recula

← Gira a la dreta

→ Gira a l’esquerra

⟲ Xucla líquid

⟳ Buida líquid

∼ Canvia de mode (saludar)

Els colors dels ulls són els mateixos que els dels blocs: qui ja hi ha jugat no ha d’aprendre res nou.

Dreta i esquerra són les del robot. Com que el teniu al davant, funciona com un mirall: feu el gest cap al vostre costat esquerre i el robot gira cap a la seva dreta. Els colors coincideixen amb els dels blocs.

Significat de la matriu de LED

Parpelleig de color Espero que confirmeu

Tic verd | Confirmat, ho faig
Creu vermella | Anul·lat
Color fix | Executant l’acció

Comandar-lo des del mòbil

1. Connecteu el robot i el mòbil a la mateixa xarxa. En un taller, el més pràctic és compartir dades des del mòbil de qui dirigeix l’activitat.

### 2. Obriu al navegador l’adreça http://adreça:8000. No

cal instal·lar cap aplicació.

Com sabeu l’adreça: la llista de dispositius connectats del punt d’accés del mòbil us la dóna. Si no hi podeu accedir, connecteu una pantalla a la sortida micro-HDMI del robot i llegiu-la-hi.

### 3. Des de la pàgina podeu:

- moure’l i girar-lo amb les fletxes
- xuclar i buidar líquid
- gravar una seqüència d’accions i executar-la després
- canviar entre mode gestos i mode blocs
- calibrar els braços i la xeringa
- apagar el robot

El comandament des del mòbil funciona sempre, tant si el robot és en mode blocs com en mode gestos.

Si alguna cosa va malament

ATURAR

El botó vermell de la pàgina atura el robot a l’instant, encara que estigui a mitja acció.
Un cop aturat podeu triar Continuar la seqüència on era, o Descartar-la i tornar a començar.

Si el robot no respon als gestos, comproveu que els braços no tapin el sensor de la cara i que sigueu en mode gestos: saludeu-lo i mireu-li els ulls.

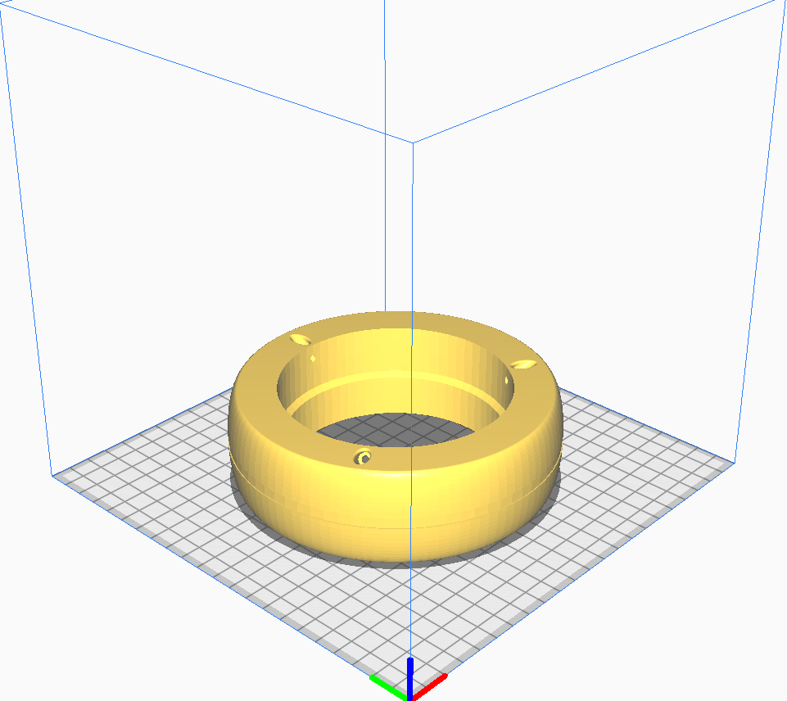
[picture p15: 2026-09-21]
3D/3D printing positioning captions/Wheel.PNG

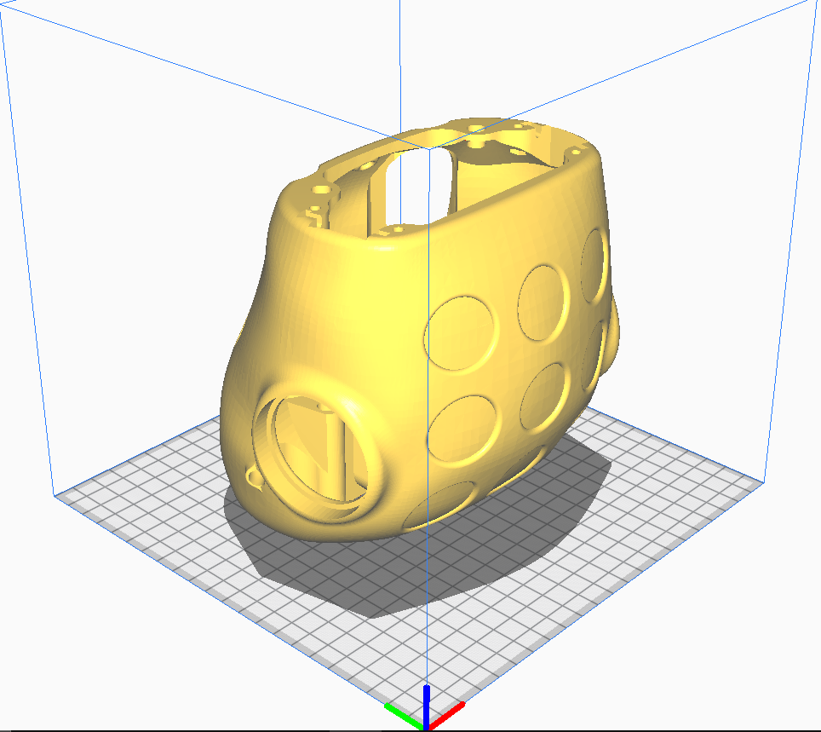
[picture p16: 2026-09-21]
3D/3D printing positioning captions/Body.PNG

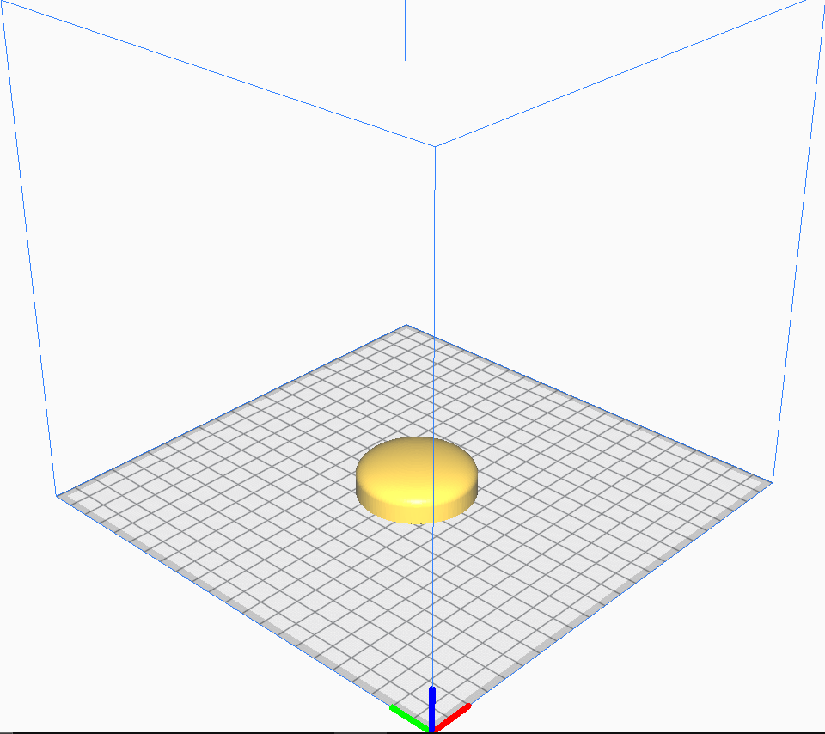
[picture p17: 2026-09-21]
3D/3D printing positioning captions/Extrude_head_3.PNG

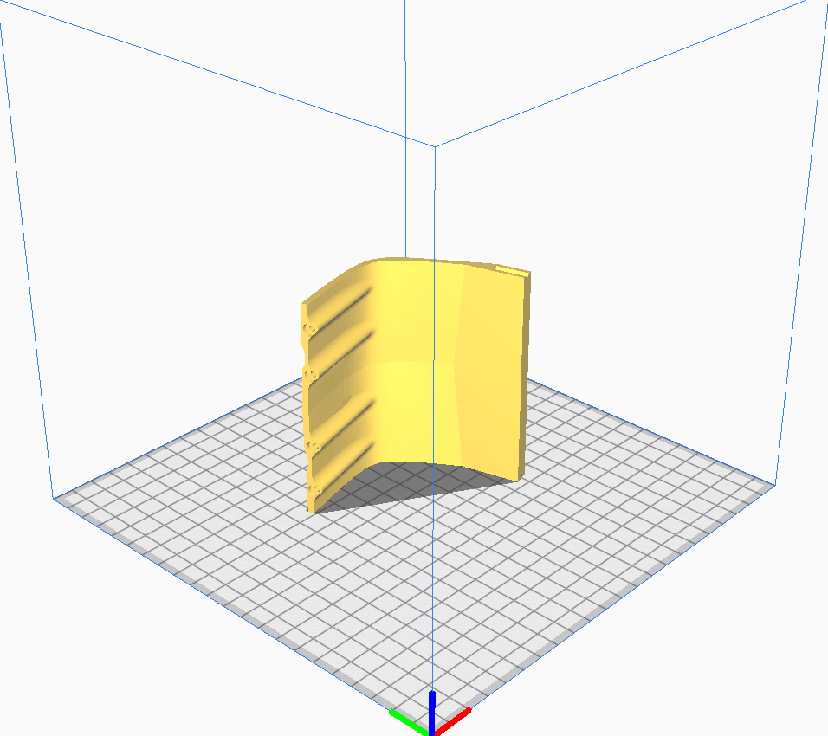
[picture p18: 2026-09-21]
3D/3D printing positioning captions/Batteries_lid.PNG

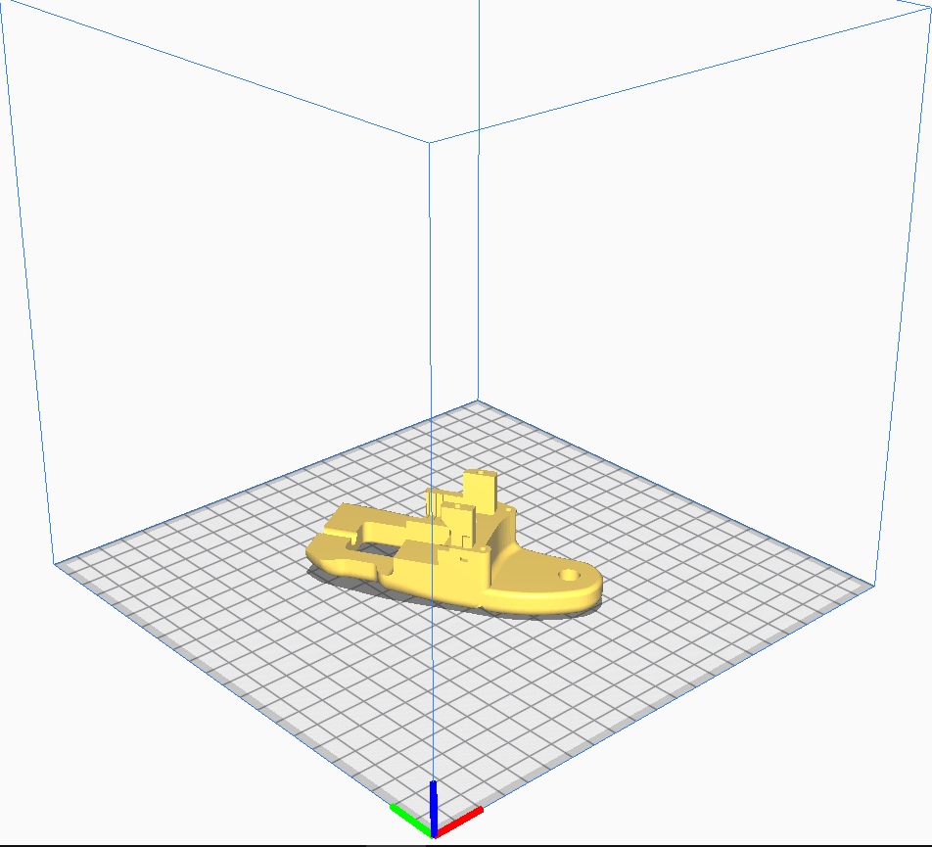
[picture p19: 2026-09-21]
3D/3D printing positioning captions/Right_assembly_support_mirror.PNG

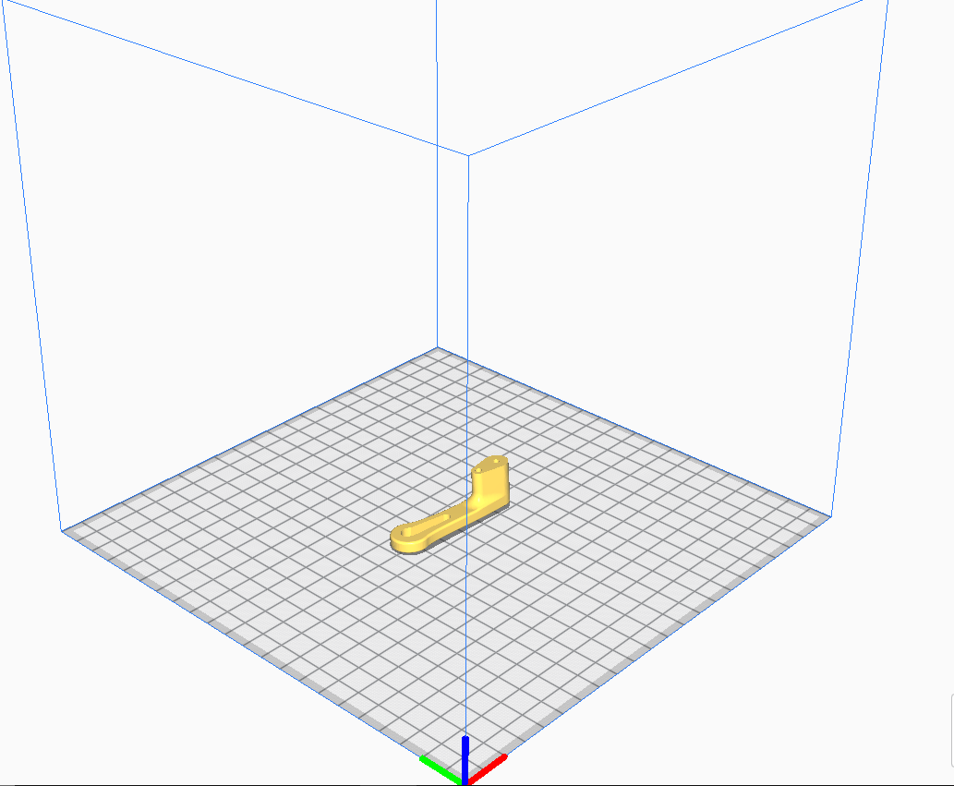
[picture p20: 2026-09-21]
3D/3D printing positioning captions/Pusher_1.PNG

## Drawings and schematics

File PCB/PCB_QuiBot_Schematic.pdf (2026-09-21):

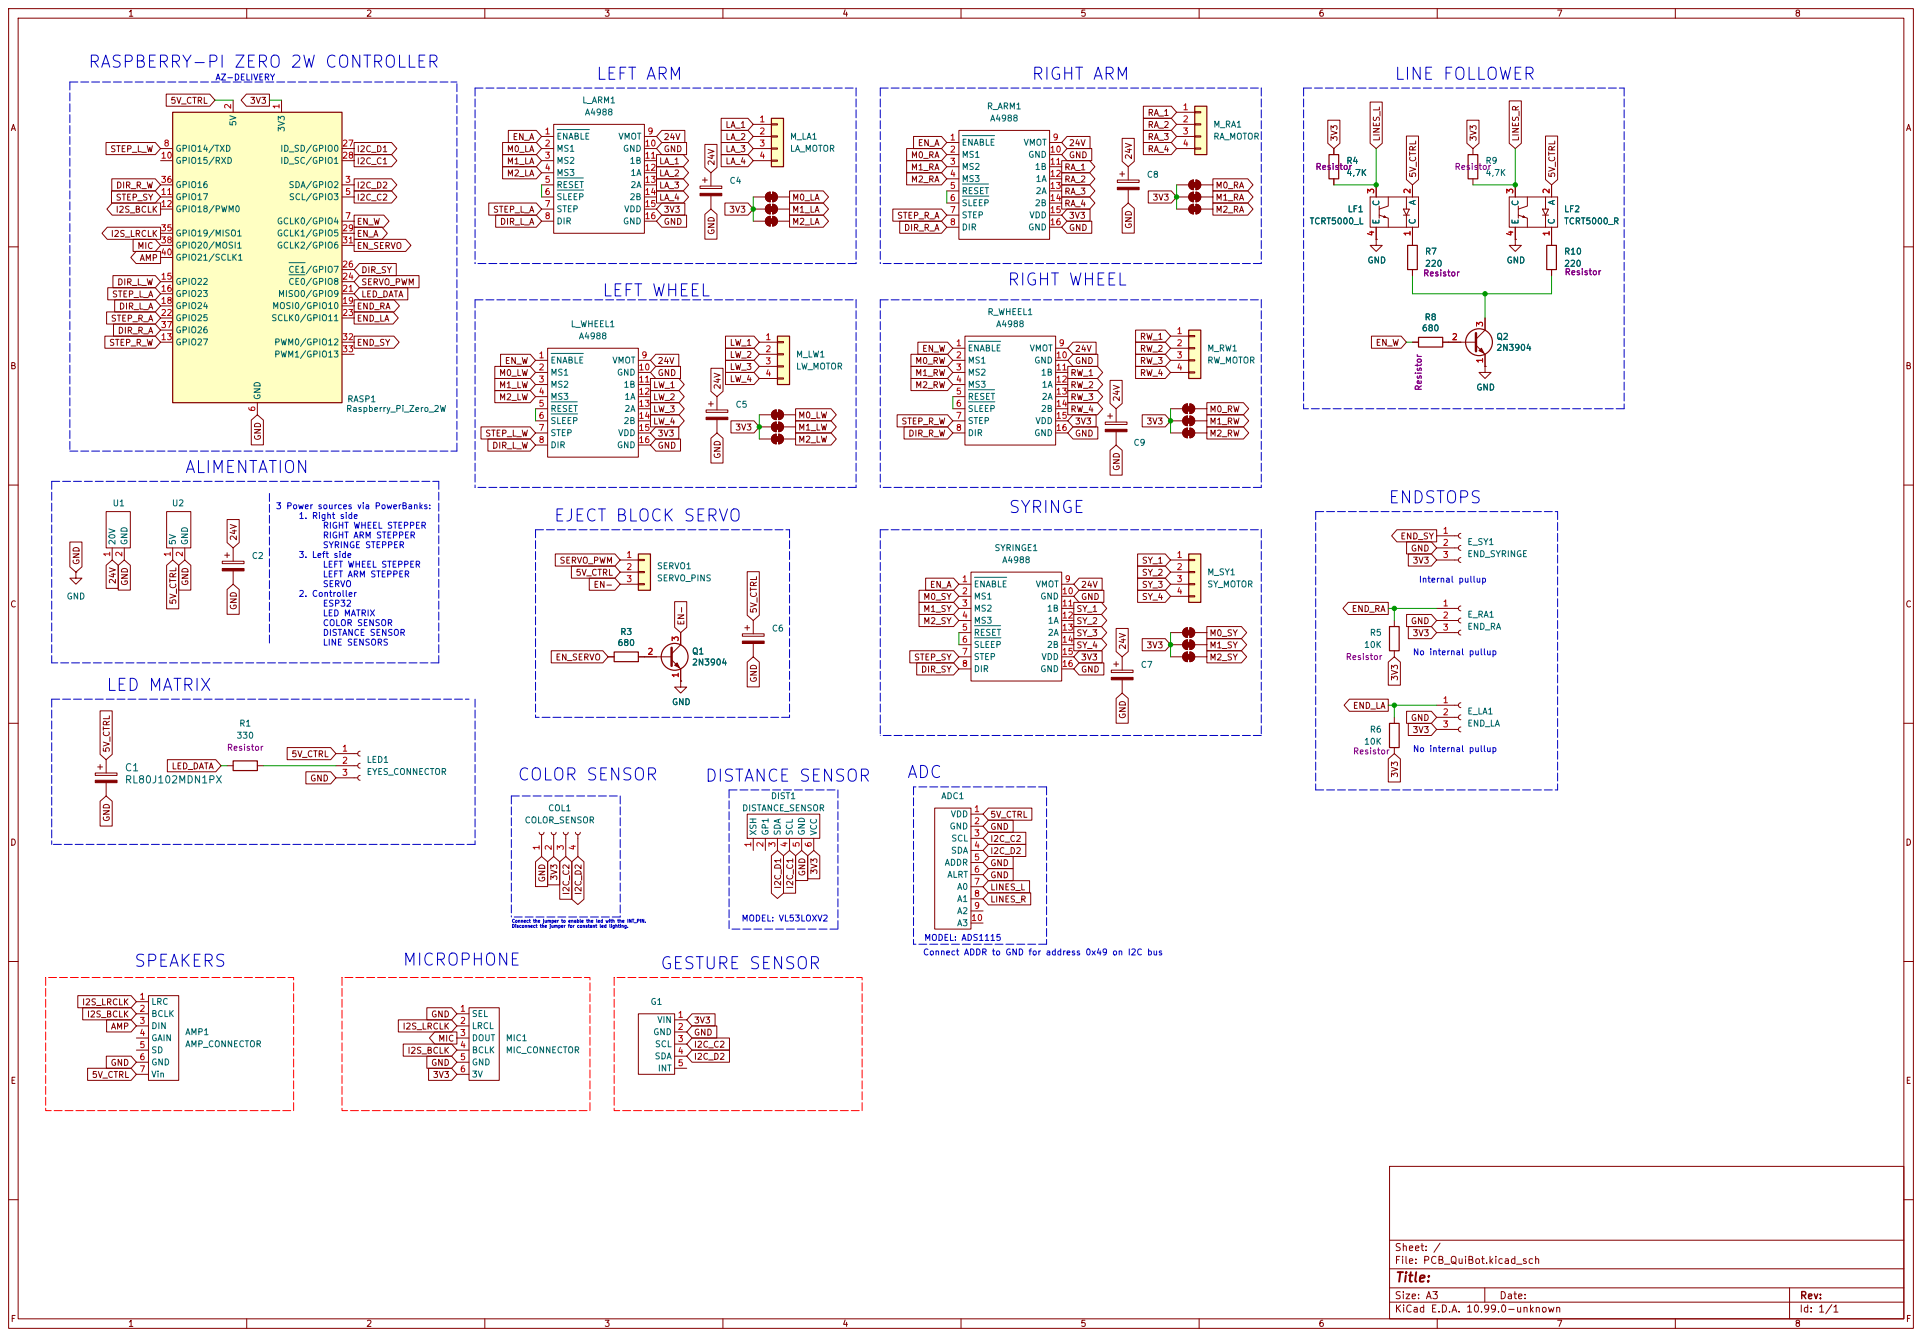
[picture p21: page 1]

RASPBERRY-PI ZERO 2W CONTROLLER

3 Power sources via PowerBanks: 1. Right side RIGHT WHEEL STEPPER

LED MATRIX COLOR SENSOR

Connect the jumper to enable the led with the INT_PIN. Disconnect the jumper for constant led lighting. MICROPHONE

MODEL: ADS1115 Connect ADDR to GND for address 0x49 on I2C bus MODEL: VL53LOXV2

Size: A3 | Rev: | F Date:
KiCad E.D.A. 10.99.0-unknown | Id: 1/1

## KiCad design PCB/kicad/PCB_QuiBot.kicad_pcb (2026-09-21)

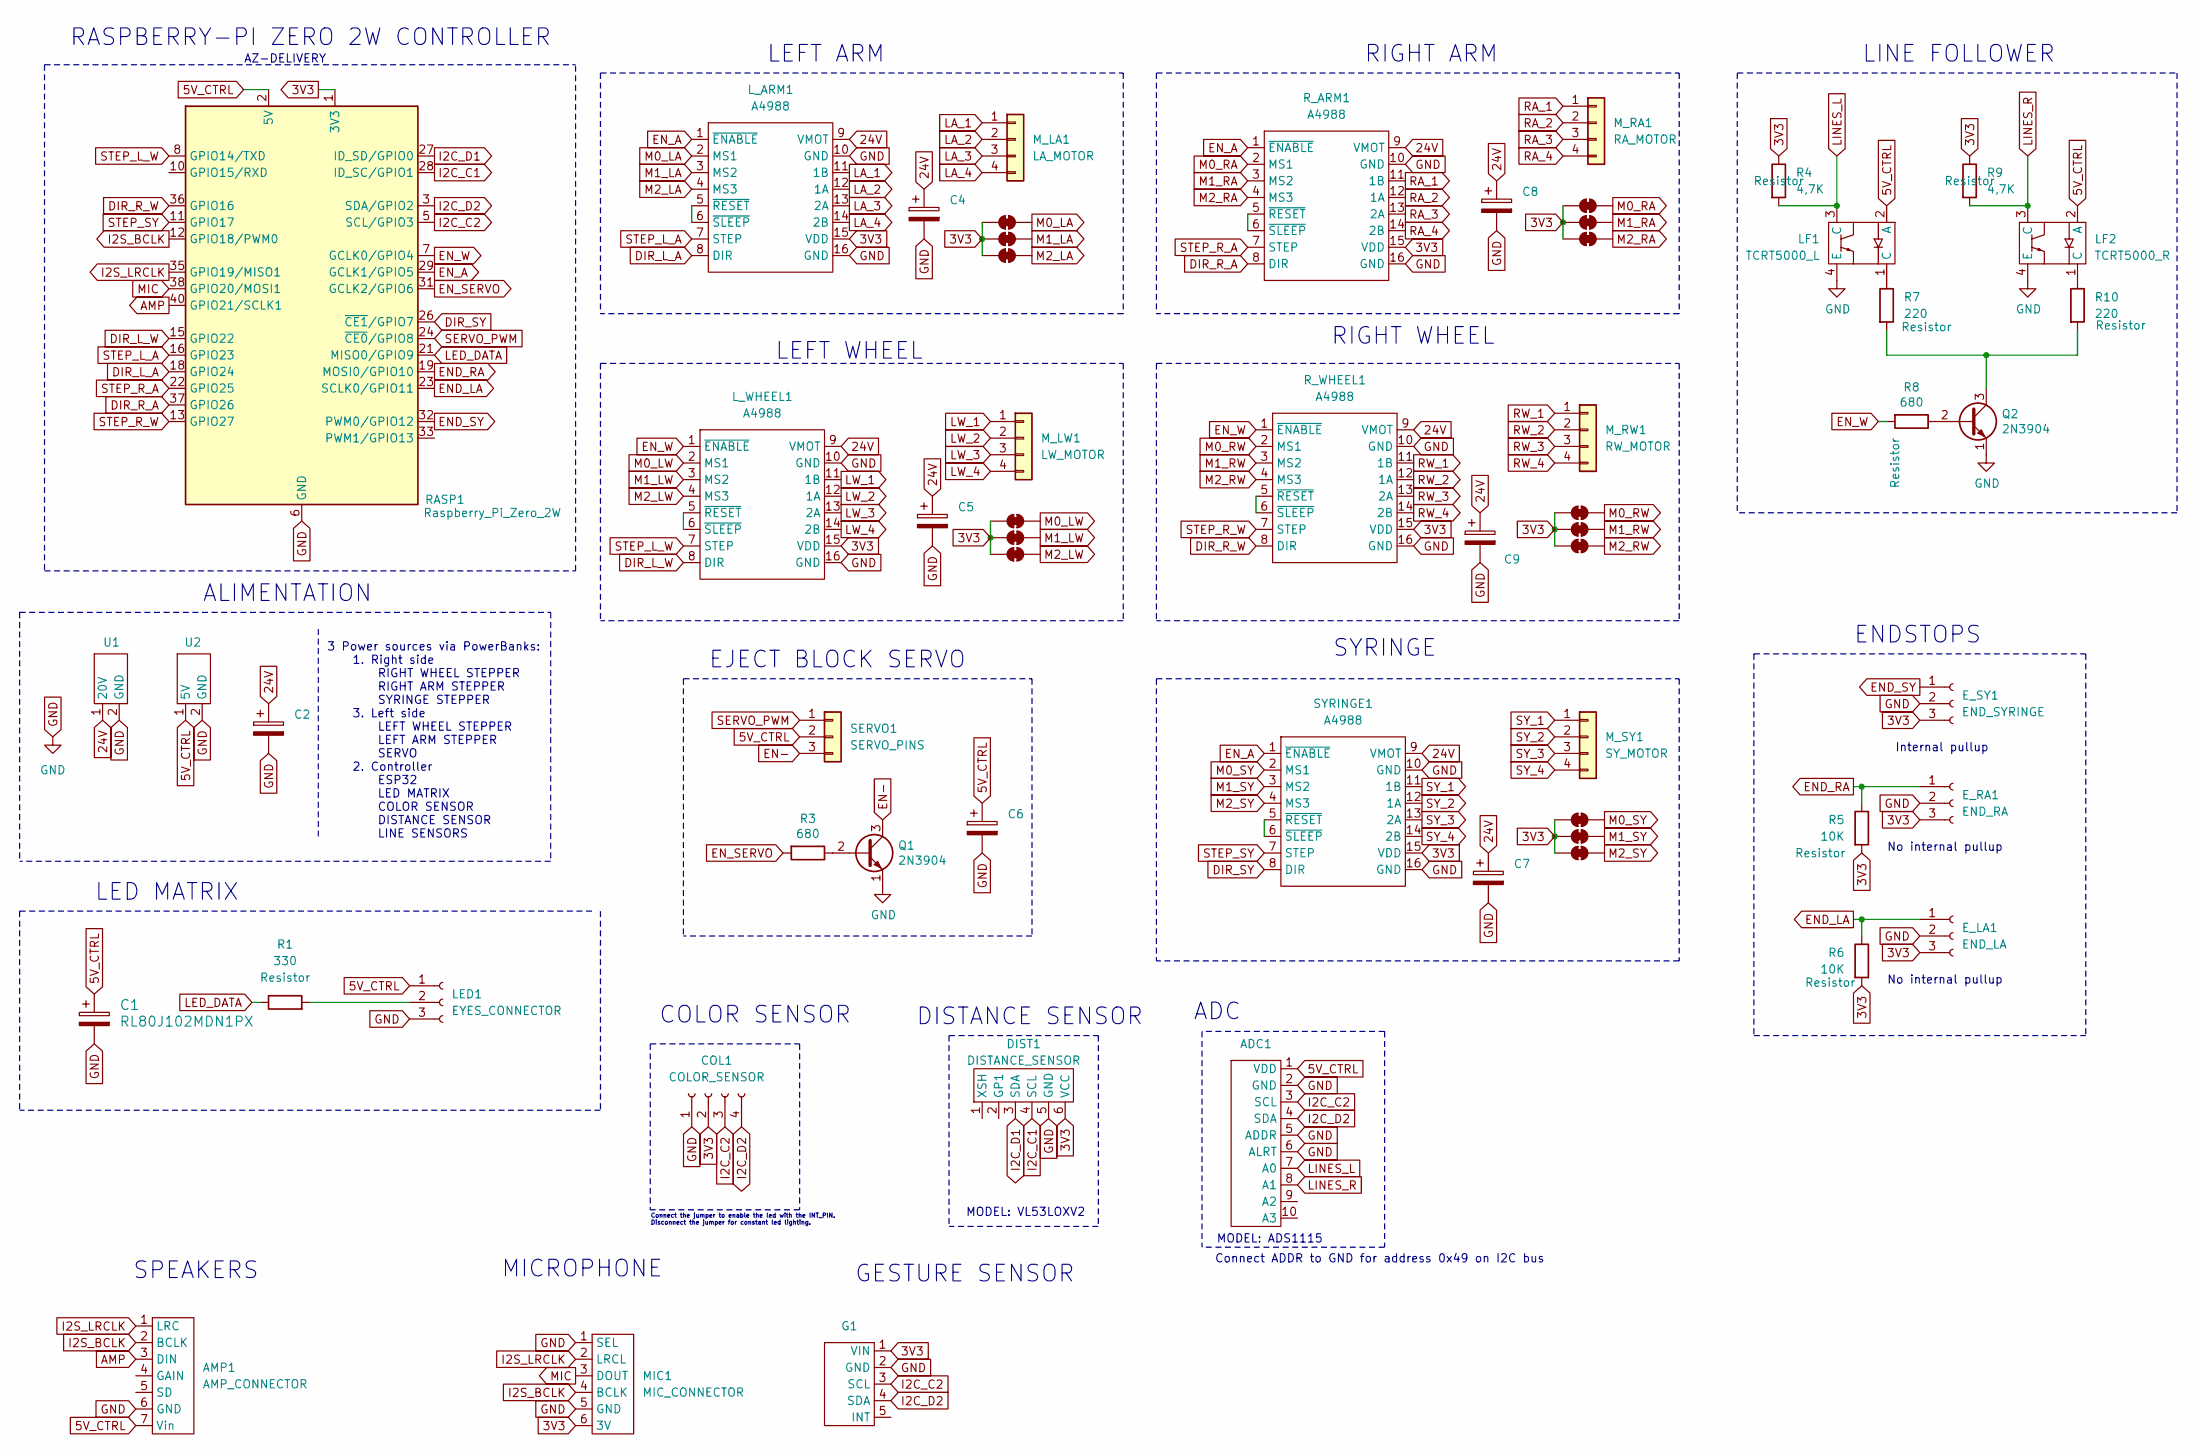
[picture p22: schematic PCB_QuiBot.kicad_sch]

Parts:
ADC1: PinHeader_1x10_P2.54mm_Vertical
AMP1: AMP_CONNECTOR; PinHeader_1x07_P2.54mm_Vertical
C1: RL80J102MDN1PX; CAP_RE5_8X8_NCH
C2: C_Polarized; CP_Radial_D10.0mm_P5.00mm
C4, C5, C6, C7, C8, C9: C_Polarized; CP_Radial_D6.3mm_P2.50mm
COL1: COLOR_SENSOR; PinHeader_1x04_P2.54mm_Vertical
DIST1: DISTANCE_SENSOR; PinHeader_1x06_P2.54mm_Vertical
E_LA1: END_LA; PinHeader_1x03_P2.54mm_Vertical
E_RA1: END_RA; PinHeader_1x03_P2.54mm_Vertical
E_SY1: END_SYRINGE; PinHeader_1x03_P2.54mm_Vertical
G1: PinHeader_1x05_P2.54mm_Vertical
LA0, LA1, LA2: SolderJumper_2_Bridged; SolderJumper-2_P1.3mm_Open_RoundedPad1.0x1.5mm
LED1: EYES_CONNECTOR; PinHeader_1x03_P2.54mm_Vertical
LF1: TCRT5000_L; TCRT5000_Line_follower
LF2: TCRT5000_R; TCRT5000_Line_follower
LW0, LW1, LW2: SolderJumper_2_Bridged; SolderJumper-2_P1.3mm_Open_RoundedPad1.0x1.5mm
L_ARM1: A4988; A4988_stepper_driver
L_WHEEL1: A4988; A4988_stepper_driver
MIC1: MIC_CONNECTOR; PinHeader_1x06_P2.54mm_Vertical
M_LA1: LA_MOTOR; PinHeader_1x04_P2.54mm_Vertical
M_LW1: LW_MOTOR; PinHeader_1x04_P2.54mm_Vertical
M_RA1: RA_MOTOR; PinHeader_1x04_P2.54mm_Vertical
M_RW1: RW_MOTOR; PinHeader_1x04_P2.54mm_Vertical
M_SY1: SY_MOTOR; PinHeader_1x04_P2.54mm_Vertical
Q1, Q2: 2N3904; TO-92_Inline
R1: 330; R_Axial_DIN0207_L6.3mm_D2.5mm_P10.16mm_Horizontal
R3, R8: 680; R_Axial_DIN0207_L6.3mm_D2.5mm_P10.16mm_Horizontal
R4, R9: 4,7K; R_Axial_DIN0207_L6.3mm_D2.5mm_P10.16mm_Horizontal
R5, R6: 10K; R_Axial_DIN0207_L6.3mm_D2.5mm_P10.16mm_Horizontal
R7, R10: 220; R_Axial_DIN0207_L6.3mm_D2.5mm_P10.16mm_Horizontal
RA0, RA1, RA2: SolderJumper_2_Bridged; SolderJumper-2_P1.3mm_Open_RoundedPad1.0x1.5mm
RASP1: Raspberry_Pi_Zero_2W; PinHeader_2x20_P2.54mm_Vertical
RW0, RW1, RW2: SolderJumper_2_Bridged; SolderJumper-2_P1.3mm_Open_RoundedPad1.0x1.5mm
R_ARM1: A4988; A4988_stepper_driver
R_WHEEL1: A4988; A4988_stepper_driver
SERVO1: SERVO_PINS; PinHeader_1x03_P2.54mm_Vertical
SY0, SY1, SY2: SolderJumper_2_Bridged; SolderJumper-2_P1.3mm_Open_RoundedPad1.0x1.5mm
SYRINGE1: A4988; A4988_stepper_driver
U1, U2: PowerConnector

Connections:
3V3: COL1.2, DIST1.6 (VCC), E_LA1.3, E_RA1.3, E_SY1.3, G1.1 (VIN), LA0.1 (A), LA1.1 (A), LA2.1 (A), LW0.1 (A), LW1.1 (A), LW2.1 (A), L_ARM1.15 (VDD), L_WHEEL1.15 (VDD), MIC1.6 (3V), R4.1, R5.2, R6.2, R9.1, RA0.1 (A), RA1.1 (A), RA2.1 (A), RASP1.1 (3V3), RASP1.17 (3V3), RW0.1 (A), RW1.1 (A), RW2.1 (A), R_ARM1.15 (VDD), R_WHEEL1.15 (VDD), SY0.1 (A), SY1.1 (A), SY2.1 (A), SYRINGE1.15 (VDD)
24V: C2.1, C4.1, C5.1, C7.1, C8.1, C9.1, L_ARM1.9 (VMOT), L_WHEEL1.9 (VMOT), R_ARM1.9 (VMOT), R_WHEEL1.9 (VMOT), SYRINGE1.9 (VMOT), U1.1 (20V)
AMP: AMP1.3 (DIN), RASP1.40 (GPIO21/SCLK1)
DIR_L_A: L_ARM1.8 (DIR), RASP1.18 (GPIO24)
DIR_L_W: L_WHEEL1.8 (DIR), RASP1.15 (GPIO22)
DIR_R_A: RASP1.37 (GPIO26), R_ARM1.8 (DIR)
DIR_R_W: RASP1.36 (GPIO16), R_WHEEL1.8 (DIR)
DIR_SY: RASP1.26 (~CE1/GPIO7), SYRINGE1.8 (DIR)
EN-: Q1.3 (C), SERVO1.3
END_LA: E_LA1.1, R6.1, RASP1.23 (SCLK0/GPIO11)
END_RA: E_RA1.1, R5.1, RASP1.19 (MOSI0/GPIO10)
END_SY: E_SY1.1, RASP1.32 (PWM0/GPIO12)
EN_A: L_ARM1.1 (~ENABLE), RASP1.29 (GCLK1/GPIO5), R_ARM1.1 (~ENABLE), SYRINGE1.1 (~ENABLE)
EN_SERVO: R3.2, RASP1.31 (GCLK2/GPIO6)
EN_W: L_WHEEL1.1 (~ENABLE), R8.2, RASP1.7 (GCLK0/GPIO4), R_WHEEL1.1 (~ENABLE)
GND: ADC1.2 (GND), ADC1.5 (ADDR), ADC1.6 (ALRT), AMP1.6 (GND), C1.2, C2.2, C4.2, C5.2, C6.2, C7.2, C8.2, C9.2, COL1.1, DIST1.5 (GND), E_LA1.2, E_RA1.2, E_SY1.2, G1.2 (GND), LED1.3, LF1.4 (E), LF2.4 (E), L_ARM1.10 (GND), L_ARM1.16 (GND), L_WHEEL1.10 (GND), L_WHEEL1.16 (GND), MIC1.1 (SEL), MIC1.5 (GND), Q1.1 (E), Q2.1 (E), RASP1.6 (GND), RASP1.9 (GND), RASP1.14 (GND), RASP1.20 (GND), RASP1.25 (GND), RASP1.30 (GND), RASP1.34 (GND), RASP1.39 (GND), R_ARM1.10 (GND), R_ARM1.16 (GND), R_WHEEL1.10 (GND), R_WHEEL1.16 (GND), SYRINGE1.10 (GND), SYRINGE1.16 (GND), U1.2 (GND), U2.2 (GND)
I2C_C1: DIST1.4 (SCL), RASP1.28 (ID_SC/GPIO1)
I2C_C2: ADC1.3 (SCL), COL1.3, G1.3 (SCL), RASP1.5 (SCL/GPIO3)
I2C_D1: DIST1.3 (SDA), RASP1.27 (ID_SD/GPIO0)
I2C_D2: ADC1.4 (SDA), COL1.4, G1.4 (SDA), RASP1.3 (SDA/GPIO2)
I2S_BCLK: AMP1.2 (BCLK), MIC1.4 (BCLK), RASP1.12 (GPIO18/PWM0)
I2S_LRCLK: AMP1.1 (LRC), MIC1.2 (LRCL), RASP1.35 (GPIO19/MISO1)
LA_1: L_ARM1.11 (1B), M_LA1.1
LA_2: L_ARM1.12 (1A), M_LA1.2
LA_3: L_ARM1.13 (2A), M_LA1.3
LA_4: L_ARM1.14 (2B), M_LA1.4
LED_DATA: R1.1, RASP1.21 (MISO0/GPIO9)
LINES_L: ADC1.7 (A0), LF1.3 (C), R4.2
LINES_R: ADC1.8 (A1), LF2.3 (C), R9.2
LW_1: L_WHEEL1.11 (1B), M_LW1.1
LW_2: L_WHEEL1.12 (1A), M_LW1.2
LW_3: L_WHEEL1.13 (2A), M_LW1.3
LW_4: L_WHEEL1.14 (2B), M_LW1.4
M0_LA: LA0.2 (B), L_ARM1.2 (MS1)
M0_LW: LW0.2 (B), L_WHEEL1.2 (MS1)
M0_RA: RA0.2 (B), R_ARM1.2 (MS1)
M0_RW: RW0.2 (B), R_WHEEL1.2 (MS1)
M0_SY: SY0.2 (B), SYRINGE1.2 (MS1)
M1_LA: LA1.2 (B), L_ARM1.3 (MS2)
M1_LW: LW1.2 (B), L_WHEEL1.3 (MS2)
M1_RA: RA1.2 (B), R_ARM1.3 (MS2)
M1_RW: RW1.2 (B), R_WHEEL1.3 (MS2)
M1_SY: SY1.2 (B), SYRINGE1.3 (MS2)
M2_LA: LA2.2 (B), L_ARM1.4 (MS3)
M2_LW: LW2.2 (B), L_WHEEL1.4 (MS3)
M2_RA: RA2.2 (B), R_ARM1.4 (MS3)
M2_RW: RW2.2 (B), R_WHEEL1.4 (MS3)
M2_SY: SY2.2 (B), SYRINGE1.4 (MS3)
MIC: MIC1.3 (DOUT), RASP1.38 (GPIO20/MOSI1)
unnamed: LED1.2, R1.2
unnamed: LF1.1 (C), R7.1
unnamed: LF2.1 (C), R10.1
unnamed: L_ARM1.5 (~RESET), L_ARM1.6 (~SLEEP)
unnamed: L_WHEEL1.5 (~RESET), L_WHEEL1.6 (~SLEEP)
unnamed: Q1.2 (B), R3.1
unnamed: Q2.2 (B), R8.1
unnamed: Q2.3 (C), R7.2, R10.2
unnamed: R_ARM1.5 (~RESET), R_ARM1.6 (~SLEEP)
unnamed: R_WHEEL1.5 (~RESET), R_WHEEL1.6 (~SLEEP)
unnamed: SYRINGE1.5 (~RESET), SYRINGE1.6 (~SLEEP)
RA_1: M_RA1.1, R_ARM1.11 (1B)
RA_2: M_RA1.2, R_ARM1.12 (1A)
RA_3: M_RA1.3, R_ARM1.13 (2A)
RA_4: M_RA1.4, R_ARM1.14 (2B)
RW_1: M_RW1.1, R_WHEEL1.11 (1B)
RW_2: M_RW1.2, R_WHEEL1.12 (1A)
RW_3: M_RW1.3, R_WHEEL1.13 (2A)
RW_4: M_RW1.4, R_WHEEL1.14 (2B)
SERVO_PWM: RASP1.24 (~CE0/GPIO8), SERVO1.1
STEP_L_A: L_ARM1.7 (STEP), RASP1.16 (GPIO23)
STEP_L_W: L_WHEEL1.7 (STEP), RASP1.8 (GPIO14/TXD)
STEP_R_A: RASP1.22 (GPIO25), R_ARM1.7 (STEP)
STEP_R_W: RASP1.13 (GPIO27), R_WHEEL1.7 (STEP)
STEP_SY: RASP1.11 (GPIO17), SYRINGE1.7 (STEP)
SY_1: M_SY1.1, SYRINGE1.11 (1B)
SY_2: M_SY1.2, SYRINGE1.12 (1A)
SY_3: M_SY1.3, SYRINGE1.13 (2A)
SY_4: M_SY1.4, SYRINGE1.14 (2B)

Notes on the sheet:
No internal pullup
ADC
ALIMENTATION
SPEAKERS
MODEL: VL53LOXV2
RIGHT WHEEL
COLOR SENSOR
EJECT BLOCK SERVO
ENDSTOPS
LEFT ARM
RASPBERRY-PI ZERO 2W CONTROLLER
Connect ADDR to GND for address 0x49 on I2C bus
MODEL: ADS1115
GESTURE SENSOR
AZ-DELIVERY
SYRINGE
LINE FOLLOWER
MICROPHONE
LEFT WHEEL
DISTANCE SENSOR
LED MATRIX
3 Power sources via PowerBanks: 1. Right side RIGHT WHEEL STEPPER RIGHT ARM STEPPER SYRINGE STEPPER 3. Left side LEFT WHEEL STEPPER LEFT ARM STEPPER SERVO 2. Controller ESP32 LED MATRIX COLOR SENSOR DISTANCE SENSOR LINE SENSORS
Internal pullup
Connect the jumper to enable the led with the INT_PIN. Disconnect the jumper for constant led lighting.
RIGHT ARM

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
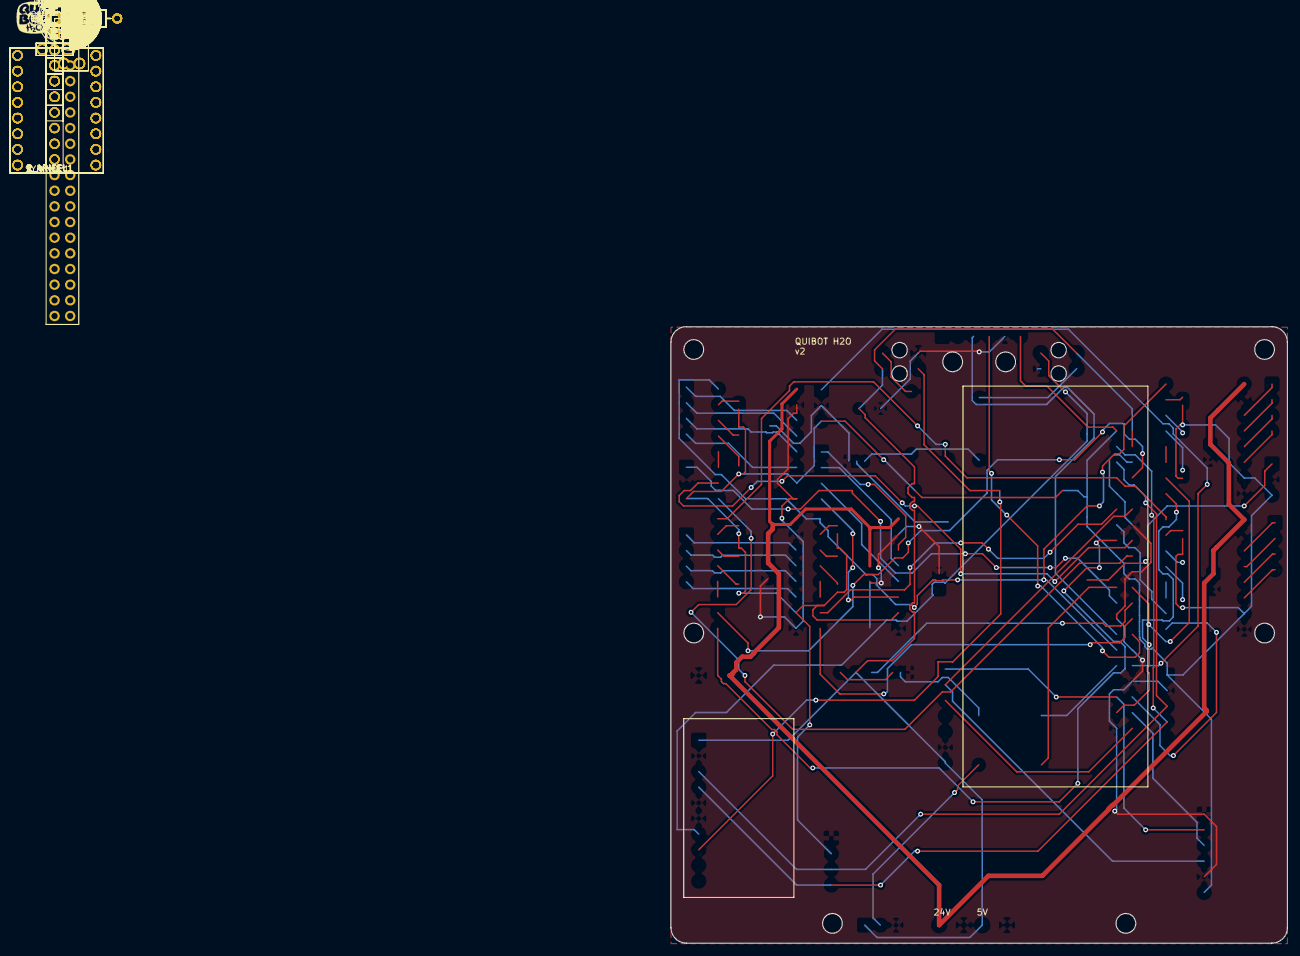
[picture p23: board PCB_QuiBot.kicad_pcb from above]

Board: 2 copper layers, 100.0 x 100.0 mm, 60 parts (0 on the bottom side), 79 nets.

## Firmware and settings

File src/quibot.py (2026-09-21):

# Copyright (C) 2026 Pau Anguera Comas
#
# Aquest programa és programari lliure: podeu redistribuir-lo i/o
# modificar-lo sota els termes de la Llicència Pública General de GNU
# publicada per la Free Software Foundation, en la versió 3.
#
# Es distribueix amb l'esperança que sigui útil, però SENSE CAP GARANTIA.
# Vegeu la Llicència Pública General de GNU per a més detalls.
# <https://www.gnu.org/licenses/>

"""
quibot.py — Programa principal del robot QuiBot H2O.
Inicialitza tots els mòduls, executa el homing i arrenca els threads.
Equivalent a QuiBot.ino del codi Arduino/ESP32.

Threads permanents:
  - task_read_blocks   → llegeix blocs i executa accions (aquest fitxer)
  - task_read_gestures → llegeix gestos i executa accions (aquest fitxer)
  - _stepper_loop      → genera polsos STEP dels motors (motion.py)
  - _task_update_leds  → parpelleig dels LEDs (eyes.py)
  - _poll_loop         → polling del sensor de gestos (gesture.py)
"""

import time
import threading
import signal
import sys
import pigpio

import motion
from motion import (
    motion_setup, motion_cleanup,
    arms_home, syringe_home, enable_arms, move_arms_up, ON,
    task_move_to, task_move_backward, task_rotate,
    task_take_or_leave_something, task_idle,
    distance_to_object,
    CROSSING, TAKE, LEAVE, CW, CCW,
)
from blocks import (
    blocks_setup,
    read_block_color, servo_move_to,
    OPEN_POSITION, EJECT_POSITION,
    BK, RD, GN, BU, YE, OG, VT,
)
from eyes import (
    eyes_setup, eyes_cleanup,
    eyes_turn_on, eyes_turn_off,
    eyes_gesture_mode_on, eyes_gesture_mode_off,
    eyes_fill, eyes_idle, eyes_blink,
    eyes_blink_color, eyes_tick, eyes_cross, eyes_mode_switch,
    EYES_OPEN, EYES_FW, EYES_DOWN,
    RED, GREEN, BLUE, YELLOW, ORANGE, CYAN, PURPLE,
)
from gesture import (
    gesture_setup, gesture_cleanup,
    read_gesture,
    GS_NONE, GS_FORWARD, GS_LEFT, GS_RIGHT,
    GS_UP, GS_DOWN, GS_CLOCKWISE, GS_ANTICLOCKWISE, GS_WAVE,
)

# ==================
# Colors addicionals (equivalents CRGB del C++)
# ==================

GRAY     = (128, 128, 128)   # CRGB::Gray     → estat normal
DARK_RED = (139,   0,   0)   # CRGB::DarkRed  → avançar

# ==================
# Timeouts
# ==================

INSERT_BLOCK_MS = 2.0   # s — espera que l'infant insereixi el bloc
EJECT_BLOCK_MS  = 2.0   # s — espera que el bloc caigui
CHECK_COLOR_MS  = 1.0   # s — interval entre lectures de color

# Interval de sondeig del sensor de gestos. Amb el robot aturat ha de ser prou
# curt perquè els gestos responguin de seguida; movent-se, el que importa és
# no robar CPU al generador de polsos, i de tota manera l'acció en curs no es
# pot interrompre amb un gest.
GESTURE_POLL_S        = 0.05
GESTURE_POLL_MOVING_S = 0.30

# Gestos: temps després d'una acció abans de tornar a escoltar (evita rebots)
GESTURE_COOLDOWN_S   = 1.2
# Temps màxim per confirmar/cancel·lar una comanda amb un gest
CONFIRM_TIMEOUT_S    = 10.0
# Durada de mostrar el tick/creu abans d'executar/cancel·lar
CONFIRM_FEEDBACK_S   = 1.6

# ==================
# Estat global
# ==================

_pi: pigpio.pi = None

# Mutex que evita que tasca de blocs i tasca de gestos llancin accions simultànies.
# En el C++ original compartien TaskHandle sense mutex explícit (possible race condition).
# Aquí ho fem correctament.
_action_lock = threading.Lock()

_shutdown_event      = threading.Event()
_gesture_mode_active = False          # False = mode blocs, True = mode gestos
_mode_lock           = threading.Lock()


# ==================
# Helper d'execució d'accions
# ==================

_busy = False


def _execute_action(fn, *args, **kwargs):
    """
    Adquireix el lock d'acció, executa fn(*args, **kwargs) de forma bloquejant
    i l'allibera. Garanteix que mai s'executen dues accions simultànies.
    """
    global _busy
    with _action_lock:
        _busy = True
        try:
            fn(*args, **kwargs)
        finally:
            _busy = False


# ==================
# Pont amb el servidor web
# ==================

class _RobotBridge:
    """
    Dona al servidor web accés controlat a l'estat del programa. S'injecta a
    webserver.bind() per no crear una dependència circular entre els mòduls.

    La web té MÉS AUTORITAT que els gestos i els blocs: pot canviar de mode i
    aturar el robot. Les accions de moviment, però, passen pel mateix lock que
    la resta, de manera que mai es trepitgen entre elles.
    """

    def execute_action(self, fn, *args, **kwargs):
        _execute_action(fn, *args, **kwargs)

    def is_busy(self):
        return _busy

    def get_mode(self):
        with _mode_lock:
            return _gesture_mode_active

    def set_mode(self, gestos: bool):
        global _gesture_mode_active
        with _mode_lock:
            canvia = _gesture_mode_active != gestos
            _gesture_mode_active = gestos
        if canvia:
            eyes_mode_switch(gestos)   # mateix senyal que en canviar-lo amb el wave
            eyes_idle()

    def request_shutdown(self):
        _shutdown_event.set()


# ==================
# Tasca de blocs
# ==================

def task_read_blocks():
    """
    Llegeix blocs contínuament, executa l'acció corresponent al color i expulsa el bloc.
    Equivalent a task_read_blocks() del FreeRTOS.
    """
    while not _shutdown_event.is_set():
        eyes_state = False
        eyes_idle()                     # repòs: ull cian amb pupil·la, esperant bloc

        # Obre el servo per permetre la inserció del bloc
        servo_move_to(OPEN_POSITION)
        time.sleep(INSERT_BLOCK_MS)

        # Espera que hi hagi un bloc i llegeix el seu color
        color_id = BK
        while not _shutdown_event.is_set():
            if distance_to_object() < 80:
                # Objecte a menys de 80mm — esperem que es retiri
                if not eyes_state:
                    eyes_idle()
                    eyes_state = True
            else:
                color_id = read_block_color()
                if eyes_state:
                    eyes_idle()
                    eyes_state = False
                if color_id != BK:
                    break
            # Mentre el robot es mou no cal llegir el color: ningú pot
            # inserir un bloc i la lectura I²C frenaria el moviment.
            while motion.moving and not _shutdown_event.is_set():
                time.sleep(0.2)
            time.sleep(CHECK_COLOR_MS)

        # Si estem en mode gestos, ignora el bloc
        with _mode_lock:
            if _gesture_mode_active:
                continue

        # Executa l'acció corresponent al color del bloc
        if color_id == RD:
            eyes_fill(RED)
            time.sleep(1.0)
            _execute_action(task_move_to, CROSSING)

        elif color_id == GN:
            eyes_fill(GREEN)
            time.sleep(1.0)
            _execute_action(task_rotate, CW)

        elif color_id == BU:
            eyes_fill(BLUE)
            time.sleep(1.0)
            _execute_action(task_rotate, CCW)

        elif color_id == YE:
            eyes_fill(YELLOW)
            time.sleep(1.0)
            _execute_action(task_take_or_leave_something, TAKE)

        elif color_id == OG:
            eyes_fill(ORANGE)
            time.sleep(1.0)
            _execute_action(task_take_or_leave_something, LEAVE)

        elif color_id == VT:
            eyes_fill(PURPLE)
            time.sleep(1.0)
            _execute_action(task_move_backward)

        eyes_idle()

        # Expulsa el bloc
        servo_move_to(EJECT_POSITION)
        time.sleep(EJECT_BLOCK_MS)


# ==================
# Tasca de gestos
# ==================

def _wait_gesture_confirmation() -> bool:
    """
    Espera un gest de confirmació mentre els ulls parpellegen la comanda.
    AMUNT = confirmar (True), AVALL = cancel·lar (False), timeout = cancel·lar.
    """
    start = time.time()
    while (time.time() - start < CONFIRM_TIMEOUT_S
           and not _shutdown_event.is_set()):
        g = read_gesture()
        if g == GS_UP:
            return True
        if g == GS_DOWN:
            return False
        time.sleep(0.05)
    return False   # timeout -> cancel·la


def task_read_gestures():
    """
    Mode gestos amb CONFIRMACIÓ:
      1) Es llegeix un gest de comanda -> els ulls PARPELLEGEN del color de la
         comanda (esperant confirmació).
      2) Gest AMUNT = confirmar (tick verd) -> executa.
         Gest AVALL = cancel·lar (creu vermella).
         Sense resposta en CONFIRM_TIMEOUT_S -> cancel·la.
      3) Després: FLUSH del buffer + COOLDOWN (no memoritza gestos fets durant
         l'acció ni encadena rebots).
    GS_WAVE (fora de confirmació) commuta mode blocs <-> gestos.

    Mapatge NATURAL (la correcció d'orientació del sensor girat es fa TOTA al
    driver gesture.py, que ja reporta el gest físic):
      UP->endavant  DOWN->enrere  LEFT->girar esquerra  RIGHT->girar dreta
      CW->buidar    CCW->xuclar
    """
    global _gesture_mode_active

    # gest de comanda -> (color dels ulls, (funció d'acció, *args))
    commands = {
        GS_UP:            (RED,    (task_move_to, CROSSING)),      # endavant
        GS_DOWN:          (PURPLE, (task_move_backward,)),         # enrere
        # ⚠️ Esquerra i dreta van INVERTIDES respecte del bloc del mateix color,
        # i és intencionat: qui fa gestos està DAVANT del robot, mirant-lo a la
        # cara, o sigui que la seva esquerra és la dreta del robot. Fer-ho com
        # un mirall és el que resulta natural per a qui el controla.
        GS_LEFT:          (GREEN,  (task_rotate, CW)),             # la seva esquerra
        GS_RIGHT:         (BLUE,   (task_rotate, CCW)),            # la seva dreta
        GS_CLOCKWISE:     (ORANGE, (task_take_or_leave_something, LEAVE)),  # buidar
        GS_ANTICLOCKWISE: (YELLOW, (task_take_or_leave_something, TAKE)),   # xuclar
    }

    while not _shutdown_event.is_set():
        # Cedir CPU SEMPRE, i molt més mentre el robot es mou. Abans, quan el
        # sensor no reportava cap gest, es tornava a llegir immediatament:
        # milers de lectures I²C per segon competint amb el generador de
        # polsos, que és el que limita la velocitat del robot.
        time.sleep(GESTURE_POLL_MOVING_S if motion.moving else GESTURE_POLL_S)

        gesture_id = read_gesture()

        # WAVE: toggle entre mode blocs i mode gestos (sense confirmació)
        if gesture_id == GS_WAVE:
            with _mode_lock:
                _gesture_mode_active = not _gesture_mode_active
                active = _gesture_mode_active
            print("Gesture mode ON" if active else "Gesture mode OFF")
            eyes_mode_switch(active)    # senyal visual del mode nou
            eyes_idle()
            time.sleep(0.4)
            read_gesture()          # flush
            continue

        with _mode_lock:
            active = _gesture_mode_active
        if not active or gesture_id not in commands:
            continue

        # --- Comanda llegida: fase de CONFIRMACIÓ ---
        color, action = commands[gesture_id]
        eyes_blink_color(color)     # parpelleja el color: esperant confirmació
        time.sleep(0.3)
        read_gesture()              # flush del gest de comanda

        if _wait_gesture_confirmation():
            eyes_tick()             # tick verd: confirmat
            time.sleep(CONFIRM_FEEDBACK_S)
            eyes_fill(color)        # color de la comanda mentre s'executa
            _execute_action(*action)
        else:
            eyes_cross()            # creu vermella: cancel·lat
            time.sleep(CONFIRM_FEEDBACK_S)

        eyes_idle()
        read_gesture()              # flush gestos fets durant l'acció (sense memòria)
        time.sleep(GESTURE_COOLDOWN_S)


# ==================
# Shutdown
# ==================

def _ip_local() -> str:
    """IP d'aquesta màquina a la xarxa, per dir per on s'hi accedeix."""
    import socket
    s = socket.socket(socket.AF_INET, socket.SOCK_DGRAM)
    try:
        s.connect(("8.8.8.8", 80))       # no envia res, només tria la ruta
        return s.getsockname()[0]
    except OSError:
        return "<ip-del-robot>"
    finally:
        s.close()


def _shutdown(sig, frame):
    print("\nAturant QuiBot...")
    _shutdown_event.set()


# ==================
# Main
# ==================

def main():
    global _pi

    # Connecta amb pigpiod (ha d'estar en marxa amb: sudo pigpiod -s 1)
    _pi = pigpio.pi()
    if not _pi.connected:
        print("ERROR: No s'ha pogut connectar a pigpiod. Executa: sudo pigpiod -s 1")
        sys.exit(1)

    # ULLS PRIMER: aixi mostrem un estat "arrencant" mentre es prepara la resta.
    # (Els LEDs es poden encendre abans que el robot estigui llest per a accions.)
    eyes_setup(_pi)
    eyes_blink()                # estat NO-PREPARAT / arrencant (ratlla blanca)

    # Inicialitza la resta de mòduls
    blocks_setup(_pi)
    motion_setup(_pi)
    gesture_setup()

    # Ni els braços ni la xeringa fan homing a l'arrencada: tots dos parteixen
    # sempre de zero. Els braços perquè, sense molles, cauen al topall en
    # apagar-se, i a més motion_cleanup() els hi baixa controladament abans;
    # la xeringa perquè acaba cada cicle a zero i el pistó no rellisca amb els
    # motors apagats. Totes dues funcions es conserven per poder recalibrar
    # sota demanda des de la interfície web.
    #   arms_home()
    #   syringe_home()
    enable_arms(ON)
    move_arms_up()      # els braços no poden tapar el sensor de gestos

    # Els ulls continuen amb l'animació de càrrega: encara falten els threads
    # i el servidor web. El senyal de "llest" es dona al final, quan de veritat
    # es pot controlar el robot.

    # Registra els senyals de sortida
    signal.signal(signal.SIGINT,  _shutdown)
    signal.signal(signal.SIGTERM, _shutdown)

    # Arrenca els threads principals
    t_blocks   = threading.Thread(target=task_read_blocks,   daemon=True, name="blocks")
    t_gestures = threading.Thread(target=task_read_gestures, daemon=True, name="gestures")

    t_blocks.start()
    t_gestures.start()

    # Servidor web: comparteix procés amb els altres dos modes, de manera que
    # tots tres veuen el mateix estat i el mateix maquinari.
    try:
        import webserver
        webserver.bind(_RobotBridge())
        threading.Thread(target=webserver.run, daemon=True, name="web").start()
        print(f"Control remot a http://{_ip_local()}:{webserver.PORT}")
    except Exception as e:                                  # noqa: BLE001
        # Que el robot funcioni encara que la web falli: gestos i blocs no
        # depenen d'ella.
        print(f"AVÍS: el servidor web no ha arrencat ({e})")

    eyes_idle()                 # ARA sí: tot en marxa, es pot controlar
    print("QuiBot llest.")

    # Espera senyal de sortida
    _shutdown_event.wait()

    # Cleanup ordenat. L'animació d'apagada va PRIMER: motion_cleanup() triga
    # uns segons baixant els braços, i durant aquella estona els ulls es
    # quedaven amb l'últim estat, com si el robot encara estigués actiu.
    eyes_blink()          # mateixa animació que a l'arrencada: "treballant"
    motion_cleanup()      # triga uns segons: baixa els braços
    eyes_cleanup()        # i ara sí, apagats (atura el fil de render i tanca)
    gesture_cleanup()
    _pi.stop()
    print("QuiBot aturat.")


if __name__ == "__main__":
    main()

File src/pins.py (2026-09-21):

# Copyright (C) 2026 Pau Anguera Comas
#
# Aquest programa és programari lliure: podeu redistribuir-lo i/o
# modificar-lo sota els termes de la Llicència Pública General de GNU
# publicada per la Free Software Foundation, en la versió 3.
#
# Es distribueix amb l'esperança que sigui útil, però SENSE CAP GARANTIA.
# Vegeu la Llicència Pública General de GNU per a més detalls.
# <https://www.gnu.org/licenses/>

"""
pins.py — Definició de pins GPIO (BCM) de la Raspberry Pi Zero 2W.

Valors extrets del connector RASP1 del projecte KiCad de la placa
(projecte-quibot-master), verificats pin a pin contra l'esquemàtic.

Tots els números fan referència a la numeració BCM.
"""

# ==================
# MOTORS (drivers A4988)
# ==================

# Enables (actius a LOW), compartits per parelles
EN_W     = 4    # enable rodes
EN_A     = 5    # enable braços
EN_SERVO = 6    # enable subsistema servo + xeringa

# Servo d'expulsió de blocs
SERVO_PWM = 8   # GPIO8 (CE0)

# Motor pas a pas xeringa
STEP_SY = 17
DIR_SY  = 7

# Motor pas a pas roda dreta
STEP_R_W = 27
DIR_R_W  = 16

# Motor pas a pas roda esquerra
STEP_L_W = 14
DIR_L_W  = 22

# Motor pas a pas braç dret
STEP_R_A = 25
DIR_R_A  = 26

# Motor pas a pas braç esquerre
STEP_L_A = 23
DIR_L_A  = 24

# ==================
# SENSORS — busos I2C
# ==================

# Bus I2C del sensor de color TCS34725 (GPIO2/3, hardware i2c-1).
# En aquest MATEIX bus hi pengen també el PAJ7620U2 (gestos) i l'ADS1115 (línia).
SDA_COL = 2
SCL_COL = 3

# Sensor de gestos PAJ7620U2 — MATEIX bus que el color (GPIO2/3)
SDA_GEST = SDA_COL
SCL_GEST = SCL_COL
# INT del PAJ7620U2 NO connectat a la PCB -> el driver usa polling

# Bus I2C del sensor de distància VL53L0X (GPIO0/1, software i2c-gpio), sol al bus
SDA_DIST = 0
SCL_DIST = 1

# Finals de carrera (efecte Hall)
END_RA = 10   # braç dret     (pullup extern 10k a la PCB)
END_LA = 11   # braç esquerre (pullup extern 10k a la PCB)
END_SY = 12   # xeringa       (SENSE pullup extern -> cal PUD_UP per software)

# Sensors seguidors de línia (TCRT5000) -> canals de l'ADS1115, NO són GPIO
LINES_L = 0   # canal AIN0 de l'ADS1115
LINES_R = 1   # canal AIN1 de l'ADS1115

# ==================
# DISPLAY
# ==================

# Dades matriu LED 8x8 RGB WS2811 (2x ull)
# Originalment a GPIO9 (a la PCB), però GPIO9 NO té PWM/PCM/SPI per hardware i
# pigpio (1µs) no pot fer el timing WS2811 (el bit "0" surt com "1" -> tot blanc).
# Solucio: pont fisic GPIO13 -> GPIO9 (GPIO13 = PWM1, valid per a rpi_ws281x) i
# LED_DATA passa a 13. IMPORTANT: GPIO9 s'ha de deixar com a ENTRADA (alta
# impedancia) perque no lluiti amb GPIO13 (ho fa eyes_setup / LED_DATA_OLD).
LED_DATA     = 13   # nou pin de dades (PWM1), via pont a la PCB
LED_DATA_OLD = 9    # pin antic; cal deixar-lo en INPUT per no fer conflicte

# ==================
# ÀUDIO (afegit per company, no part d'aquest TFG)
# ==================

# I2S — amplificador + micròfon
I2C_BCLK  = 18
I2C_LRCLK = 19
MIC       = 20
AMP_DIN   = 21

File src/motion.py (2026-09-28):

# Copyright (C) 2026 Pau Anguera Comas
#
# Aquest programa és programari lliure: podeu redistribuir-lo i/o
# modificar-lo sota els termes de la Llicència Pública General de GNU
# publicada per la Free Software Foundation, en la versió 3.
#
# Es distribueix amb l'esperança que sigui útil, però SENSE CAP GARANTIA.
# Vegeu la Llicència Pública General de GNU per a més detalls.
# <https://www.gnu.org/licenses/>

"""
motion.py — Control de motors (rodes, braços, xeringa), sensor de distància
            VL53L0X i seguidor de línia TCRT5000 via ADS1115.
Equivalent a motion.cpp del codi Arduino/ESP32.
"""

import math
import time
import threading
import pigpio
import adafruit_extended_bus
import adafruit_vl53l0x
import adafruit_ads1x15.ads1115 as ADS
from adafruit_ads1x15.analog_in import AnalogIn

from pins import (
    STEP_R_W, DIR_R_W, STEP_L_W, DIR_L_W, EN_W,
    STEP_R_A, DIR_R_A, STEP_L_A, DIR_L_A, EN_A,
    STEP_SY,  DIR_SY,  EN_SERVO,
    END_SY, END_RA, END_LA,
)

# ==================
# Constants
# ==================

CW    = True
CCW   = False
ON    = 0       # A4988/TB6600: enable actiu en LOW
OFF   = 1
TAKE  = True
LEAVE = False

# Tipus de resposta del seguidor de línia
CLEAR    = 0
CROSSING = 1
OBJECT   = 2

# Noms de tasques (equivalent a les constants string del C++)
MOVE_TO_CROSSING  = "Move to crossing"
TURN_90_CW        = "Turn 90 CW"
TURN_90_CCW       = "Turn 90 CCW"
MOVE_TO_OBJECT    = "Move to object"
TAKE_SOMETHING    = "Take something"
LEAVE_SOMETHING   = "Leave something"
DO_NOTHING        = "Do nothing"

# Paràmetres de moviment
# 250 passos/s = 125 mm/s (1 mm = 2 passos). Acceleració 800: arriba a la
# velocitat en 0,31 s (uns 20 mm dels 300 del tram entre vèrtexs).
# El límit el posa el generador de polsos, no els motors: mesurat 2026-09-07
# amb la Raspberry nova, se satura a ~390 passos/s per roda (igual que
# l'anterior). Durant el seguiment de línia la roda de fora rep
# velocitat + correcció (màxim ~123 amb error 16000 i P_FACTOR=130), o sigui
# 250 + 123 = 373, que hi cap. A 350 en demanaria 473 i la correcció es
# retallaria en silenci: el robot giraria menys del que el control comanda.
WHEELS_MAX_SPEED  = 175.0   # steps/s
WHEELS_ACCEL      = 800.0   # steps/s²
ARMS_MAX_SPEED    = 250.0   # steps/s
ARMS_ACCEL        = 125.0   # steps/s²
# Velocitat de la xeringa. Baixada de 800 a 400 el 2026-09-10: movent aigua,
# el motor perdia passos. Un pas a pas perd parell a mesura que puja de
# revolucions, i alentir-lo és la primera palanca abans de tocar el Vref.
# Ajustada a 350 el 2026-09-10: amb aigua va bé i no cal tocar el Vref.
SYRINGE_MAX_SPEED = 350.0   # steps/s
SYRINGE_ACCEL     = 500.0   # steps/s²

WHEEL_MECH_REDUCTION       = 5
WHEEL_STEPS_PER_REVOLUTION = 200 * WHEEL_MECH_REDUCTION   # 1000 passos/volta de roda

# Distància que avança el robot des que detecta la cruïlla fins que l'eix de
# les rodes queda sobre el vèrtex, que és el punt sobre el qual ha de pivotar
# per encarar bé la línia perpendicular. Es compon de la separació física
# entre els sensors i l'eix (54 mm, mesurada) més el tram que queda des que
# el sensor entra a la cinta fins al centre d'aquesta (uns 6 mm).
# Ajustat de 62 a 60 el 2026-09-07 i de 60 a 57 el 2026-09-08: en el
# recorregut complet, el robot continuava avançant una mica de més abans de
# girar.
MM_TO_CROSSING_CENTER = 57
# Distància que avança el robot des del vèrtex fins a quedar davant del
# recipient, seguint la línia.
#
# El recipient sempre és al vèrtex següent i el robot sempre parteix d'un
# vèrtex, o sigui que aquesta distància és FIXA i es compta en passos. El
# sensor de distància NO s'usa per aturar-se: el seu paper és només dir si hi
# ha recipient o no (comprovació prèvia, amb el robot quiet), que és el que fa
# bé. Aturar-se pel sensor donava parades diferents cada vegada, perquè el
# punt on detectava variava amb la reflexió del tuper transparent.
# Calibrat al taulell el 2026-09-10: 140 mm.
MM_TO_OBJECT          = 140

# Distància a la qual es considera que hi ha un objecte al davant. Estava
# escrita dins de follow_line_loop() i no es podia ajustar sense editar el
# codi. ⚠️ El sensor de gestos treballa amb la mà a uns 15 cm: cal comprovar
# que una persona a prop no dispari aquesta detecció.
# Distància a la qual es considera que hi ha un objecte al davant.
#
# Pujada de 50 a 80 el 2026-09-10: la parada no era repetible. Com més a prop
# mesura el VL53L0X, més li afecten l'error relatiu i les variacions de
# reflexió del tuper (que a més és transparent). Detectant més lluny el senyal
# és més estable, i com que el tram que ve després és una distància fixa
# comptada en passos, el robot acaba sempre al mateix lloc.
OBJECT_DISTANCE_MM = 80

# Mínim físic del VL53L0X. Qualsevol mesura per sota d'aquest valor no és una
# distància, és una lectura invàlida: el sensor no pot mesurar tan a prop.
# Se n'han vist de 0 mm amb l'estat marcat com a bo.
DIST_MIN_VALID_MM = 30

# Una detecció d'objecte només es dona per bona si la mesura ANTERIOR ja el
# veia per sota d'aquest valor. Un objecte real no apareix de cop: acostant-s'hi
# a 75 mm/s amb una mesura cada ~195 ms, el robot només avança 15 mm entre
# lectures, de manera que abans d'estar a 80 mm ha d'haver passat per 150 i
# per 250. En canvi una lectura errònia salta de "fora de rang" a 150 mm d'una
# tirada. Aquesta condició les descarta sense endarrerir la parada, perquè amb
# un objecte real ja es compleix des de molt abans.
OBJECT_TRACK_MM = 250
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

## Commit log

2026-09-21 Qui-Bot H2O: maquinari, programari i documentació
    Publicació del projecte en obert: peces 3D, projecte KiCad i fitxers de
    fabricació, programa de control amb reconeixement de gestos i control remot
    per Wi-Fi, llista de material i manual d'ús.
    [3D_Parts_list.ods, Arms_motors_support_bottom.STL, Arms_motors_support_top.STL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]
2026-09-21 Capçaleres de llicència GPLv3 als fitxers de codi
2026-09-21 Fitxers de disseny SolidWorks de les dues peces modificades
    [Batteries_support.SLDPRT]
2026-09-28 Model del conjunt en FreeCAD i vídeo de demostració
2026-09-28 Actualitza el comentari de la detecció d'objectes al seguidor de línia
2026-09-28 Actualitza la memòria
2026-10-01 Actualitza el resum i l'abstract de la memòria
